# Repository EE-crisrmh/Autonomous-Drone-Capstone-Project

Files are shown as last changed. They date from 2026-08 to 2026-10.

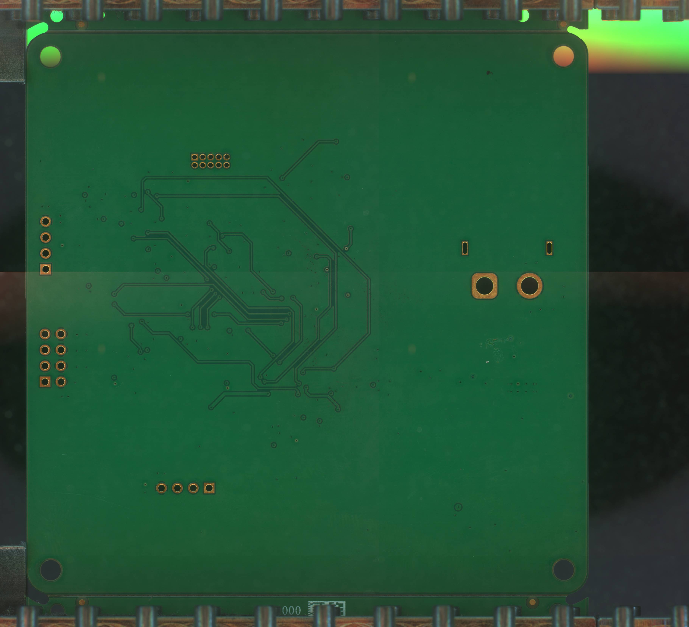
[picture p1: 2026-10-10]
Hardware/images/FlightControllerv1.0_bottom.jpg

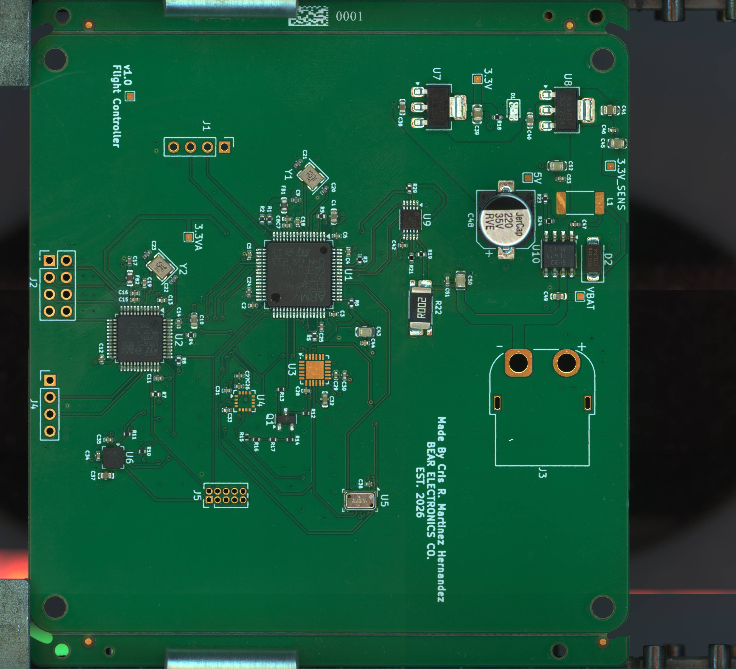
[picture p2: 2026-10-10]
Hardware/images/FlightControllerv1.0_top.jpg

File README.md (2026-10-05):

# LumaWay 🌄

> **A GPS-guided autonomous drone system that guides lost hikers back to safety.**

---

## The Problem

Every year, thousands of hikers get lost on trails across the United States. Terrain looks the same in every direction. Cell service is gone. Panic sets in. Search and rescue teams can take hours to respond — and in the mountains, hours matter.

Current solutions require hikers to stay still and wait. LumaWay flips that. Instead of waiting to be found, the hiker gets found — and then guided home.

---

## What LumaWay Does

LumaWay is an autonomous drone system built for one purpose: get a lost hiker back on the trail.

Here's how it works:

1. **Before the hike**, the hiker opens the LumaWay app and starts a session. The app passively records their GPS trail as they walk in — no interaction needed, just like a fitness tracker running in the background.

2. **If they get lost**, they hit the SOS button. The app sends their current GPS location and their recorded trail path to the LumaWay ground station.

3. **The drone launches autonomously**, navigates to the hiker's GPS coordinates, and locates them.

4. **LumaWay leads them out.** The drone flies the recorded trail path in reverse — slowly, at walking pace — using a bright LED and audio signal to guide the hiker back to the trailhead. Follow the light. That's it.

No payload to drop. No complex robotics. Just a reliable, visible guide in the sky when you need it most.

---

## Why a Drone

A drone can cover terrain a person can't. It flies over downed trees, river crossings, and steep ridgelines. It doesn't get lost. It doesn't get tired. And it can reach a hiker in minutes rather than hours.

LumaWay isn't trying to replace search and rescue — it's a first response that buys time, reduces panic, and gets people moving in the right direction before conditions get worse.

---

## The System

LumaWay is built across three integrated components:

**Custom Flight Controller (Hardware)**
A 4-layer custom PCB built around dual STM32 microcontrollers — one for navigation, one for I/O. Onboard sensors include dual IMUs (ICM-20689, ICM-20602), a barometer (MS5611), and a magnetometer (IST8310) for full attitude and altitude awareness. Designed and manufactured in-house.

**Onboard Computing (Autonomy)**
An NVIDIA Jetson Nano handles high-level autonomy — GPS waypoint navigation, computer vision for hiker confirmation, and communication with the ground station over a wireless link.

**LumaWay App (Interface)**
A mobile app for hikers. Records the trail on the way in. Sends SOS with one tap. Shows the drone's live position on a map so rescue coordinators can monitor the situation in real time.

---

## Project Goals

- Demonstrate fully autonomous GPS-guided navigation to a target location
- Achieve stable hover and guided return-path flight in outdoor conditions
- Build a functional mobile app with trail recording and SOS capability
- Integrate onboard vision for hiker detection and confirmation
- Complete a full end-to-end demo: SOS sent → drone launches → hiker guided back

---

## Status

🔧 **In development** — UW Bothell Capstone Project, 2026–2027

---

## Team

Built by a four-person Electrical Engineering capstone team at the University of Washington Bothell, supervised by Dr. Hannachi.

- Cris R. Martinez Hernandez
- Abraham Chen
- Frank Ma
- Howard Sin

---

## Built With

- STM32F405 / STM32F103 (flight controller MCUs)
- NVIDIA Jetson Nano (onboard compute)
- T-Motor MN2806 Antigravity motors
- KiCad (PCB design)
- PlatformIO (firmware)
- Python / OpenCV (computer vision)
- React Native (mobile app)

---

*LumaWay — your way home made easy*

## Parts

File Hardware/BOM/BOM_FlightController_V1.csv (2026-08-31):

Reference designator | Value | Package | LCSC Part # | MPN | Manufacturer | Description | Cost
C24, C25, C27, C30 | 2.2 uF | 402 | C107369 | CL05A225KP5NSNC | Samsung Electro-Mechanics | 2.2uF 10V X5R ceramic cap | 0.0042
C1, C10, C38, C40, C49 | 10uF | 603 | C19702 | CL10A106KP8NNNC | Samsung Electro-Mechanics | CAP CER 10uF 10V X5R 0603 | 0.0125
C2, C3, C4, C5, C6, C7, C8, C11, C12, C13, C14, C15, C16, C18, C19, C26, C29, C33-C36, C42, C44, C46, C51, C53 | 100nF | 402 | C1525 | CL05B104KO5NNNC | Samsung Electro-Mechanics | CAP CER 100nF 16V X7R 0402 | 0.16
C9, C17 | 1uF | 402 | C29266 | CL05A105KO5NNNC | Samsung Electro-Mechanics | CAP CER 1uF 16V X5R 0402 | 0.35
C20, C21, C22, C23 | 10pF | 402 | C32949 | CL05C100JB5NNNC | Samsung Electro-Mechanics | CAP CER 10pF 50V C0G 0402 | 0.24
C28, C31, C47 | 10nF | 402 | C15195 | CL05B103KB5NNNC | Samsung Electro-Mechanics | CAP CER 10nF 50V X7R 0402 | 0.16
C32 | 0.47uF | 603 | C1623 | CL10B474KA8NNNC | Samsung Electro-Mechanics | CAP CER 470nF 25V X7R 0603 | 0.74
C37 | 4.7uF | 603 | C19666 | CL10A475KO8NNNC | Samsung Electro-Mechanics | CAP CER 4.7uF 16V X5R 0603 | 0.12
C39, C41 | 22uF | 805 | C5674 | CL21A226MQQNNNE | Samsung Electro-Mechanics | CAP CER 22uF 6.3V X5R 0805 | 0.28
C43, C45, C50, C52 | 47uF | 805 | C16780 | CL21A476MQYNNNE | Samsung Electro-Mechanics | CAP CER 47uF 6.3V X5R 0805 | 0.56
C48 | 220uF | SMD,D8xL10.5mm | C48935405 | RVE35V220M8X10 | JIERR | CAP ALUM 220uF ±20% 35V SMD | 0.41
D1 | RED | 805 | C19171391 | YLED0805R | YONGYUTAI | LED RED 0805 SMD | 0.82
D2 | B340 | SMA(DO-214AC) | C908680 | SS34 | GOODWORK | DIODE SCHOTTKY 40V SMA(DO-214AC) | 0.53
FB1, FB2 | 120 ohm | 603 | C14709 | BLM18PG121SN1D | muRata | FERRITE BEAD 120Ω 0603 1LN | 0.74
J1 | connector | Through Hole,P=2.54mm | C32713270 | HX PZ2.54-1x4P ZZ | hanxia | CONN HEADER 4POS 2.54mm SINGLE ROW TH | 0.13
J2 | connector | Through Hole,P=2.54mm | C32713277 | HX PZ2.54-2x4P ZZ | hanxia | CONN HEADER 8POS 2.54mm DUAL ROW TH | 0.6
J4 | connector | Through Hole,P=2.54mm | C32713270 | HX PZ2.54-1x4P ZZ | hanxia | CONN HEADER 4POS 2.54mm SINGLE ROW TH | 0.13
J5 | connector | Through Hole,P=1.27mm | C41426986 | A127M01-0B10P51-H10A39 | JXTCONN | CONN HEADER 10POS DUAL ROW TH | 0.38
L1 | 15uH | 2512 SMD,7x6.6mm | C5349699 | APH0630T150M | APV | FIXED IND 15uH 3A 113mΩ SMD,7x6.6mm | 0.4
Q1 | 20V 350mA NPN transistor | SOT-23 | C916372 | MMBT2222A | JSMSEMI | TRANS NPN 20V 350mA SOT-23 | 0.56
R1, R2, R3, R4, R5, R6, R7, R8, R9, R19, R20, R23 | 10k | 603 | C2930027 | FRC0603J103 TS | FOJAN | RES 10kΩ ±5% 100mW 0603 | 0.14
R10, R11 | 4.7k | 603 | C99782 | RC0603FR-074K7L | YAGEO | RES 4.7kΩ ±1% 100mW 0603 | 0.23
R12, R13, R14, R15, R16, R17 | 1.8 ohm | 603 | C2907087 | FRC0603J1R8 TS | FOJAN | RES 1.8Ω ±5% 100mW 0603 | 0.2
R18 | 1k | 402 | C852624 | RT0402BRD071KL | YAGEO | RES 1kΩ ±0.1% 62.5mW 0402 | 1
R21 | 3.3k | 402 | C482167 | CRCW04023K30FKED | VISHAY | RES 3.3kΩ ±1% 63mW 0402 | 0.4
R22 | 2m | 2512 | C2994640 | HoLLR2512-3W-2mR-1% | Milliohm | RES 2mΩ ±1% 3W 2512 | 0.33
R24 | 3.24k | 402 | C3972407 | CRCW04023K24FKED | VISHAY | RES 3.24kΩ ±1% 62.5mW 0402 | 0.42
U1 | STM32F405RGTx | LQFP-64(10x10) | C1337199 | STM32F405RGT7 | ST | Arm Cortex - M4 32b | 12.83
U2 | STM32F103C8Tx | LQFP-48(7x7) | C8734 | STM32F103C8T6 | ST | Arm-Based 32b | 1.44
U3 | ICM-20689 | QFN-24-EP(4x4) | C2649494 | ICM-20689 | TDK InvenSense | 6-axis MEMS motion tracking | 16.5
U4 | ICM-20602 | LGA-16(3x3) | C97633 | ICM-20602 | TDK InvenSense | 6-Axis MEMS motion tracking | 16.5 | Not available rn
U5 | MS5611-01BA | QFN-8(3x5) | C15639 | MS561101BA03-50 | TE Connectivity | Barometric preassure sensor | 7.11 | Not available rn
U6 | IST8310 | LGA-16(3x3) | C2683055 | IST8310 | iSentek | 3D Magnetometer | 5.63 | U5 MS5611 footprint may have minor QFN vs LGA package discrepancy, please verify pad alignment.
U7, U8 | AMS1117-3.3 | SOT-223 | C5205141 | AMS1117-3.3V | JSMSEMI | 800mA Bipolar Linear Regulator | 0.4
U9 | INA226 | VSOP-10 | C49851 | INA226AIDGSR | TI | Bi-Directional CURRENT/POWER MONITOR with I2C Interface | 0.79
U10 | TPS5430DDA | SOIC-8-EP | C9864 | TPS5430DDAR | TI | 3-A, Wide Input Range, Step-Down Converter | 0.81
Y1, Y2 | 16MHz | SMD3225-4P | C13738 | X322516MLB4SI | YXC Crystal Oscillators | CRYSTAL 16MHz 9pF SMD | 0.49
J3 | connector | AMASS XT60PW-F 1x02 P7.20mm Horizontal | C428722 | XT60PW-F | Changzhou Amass Elec | Power Connectors | 0.64

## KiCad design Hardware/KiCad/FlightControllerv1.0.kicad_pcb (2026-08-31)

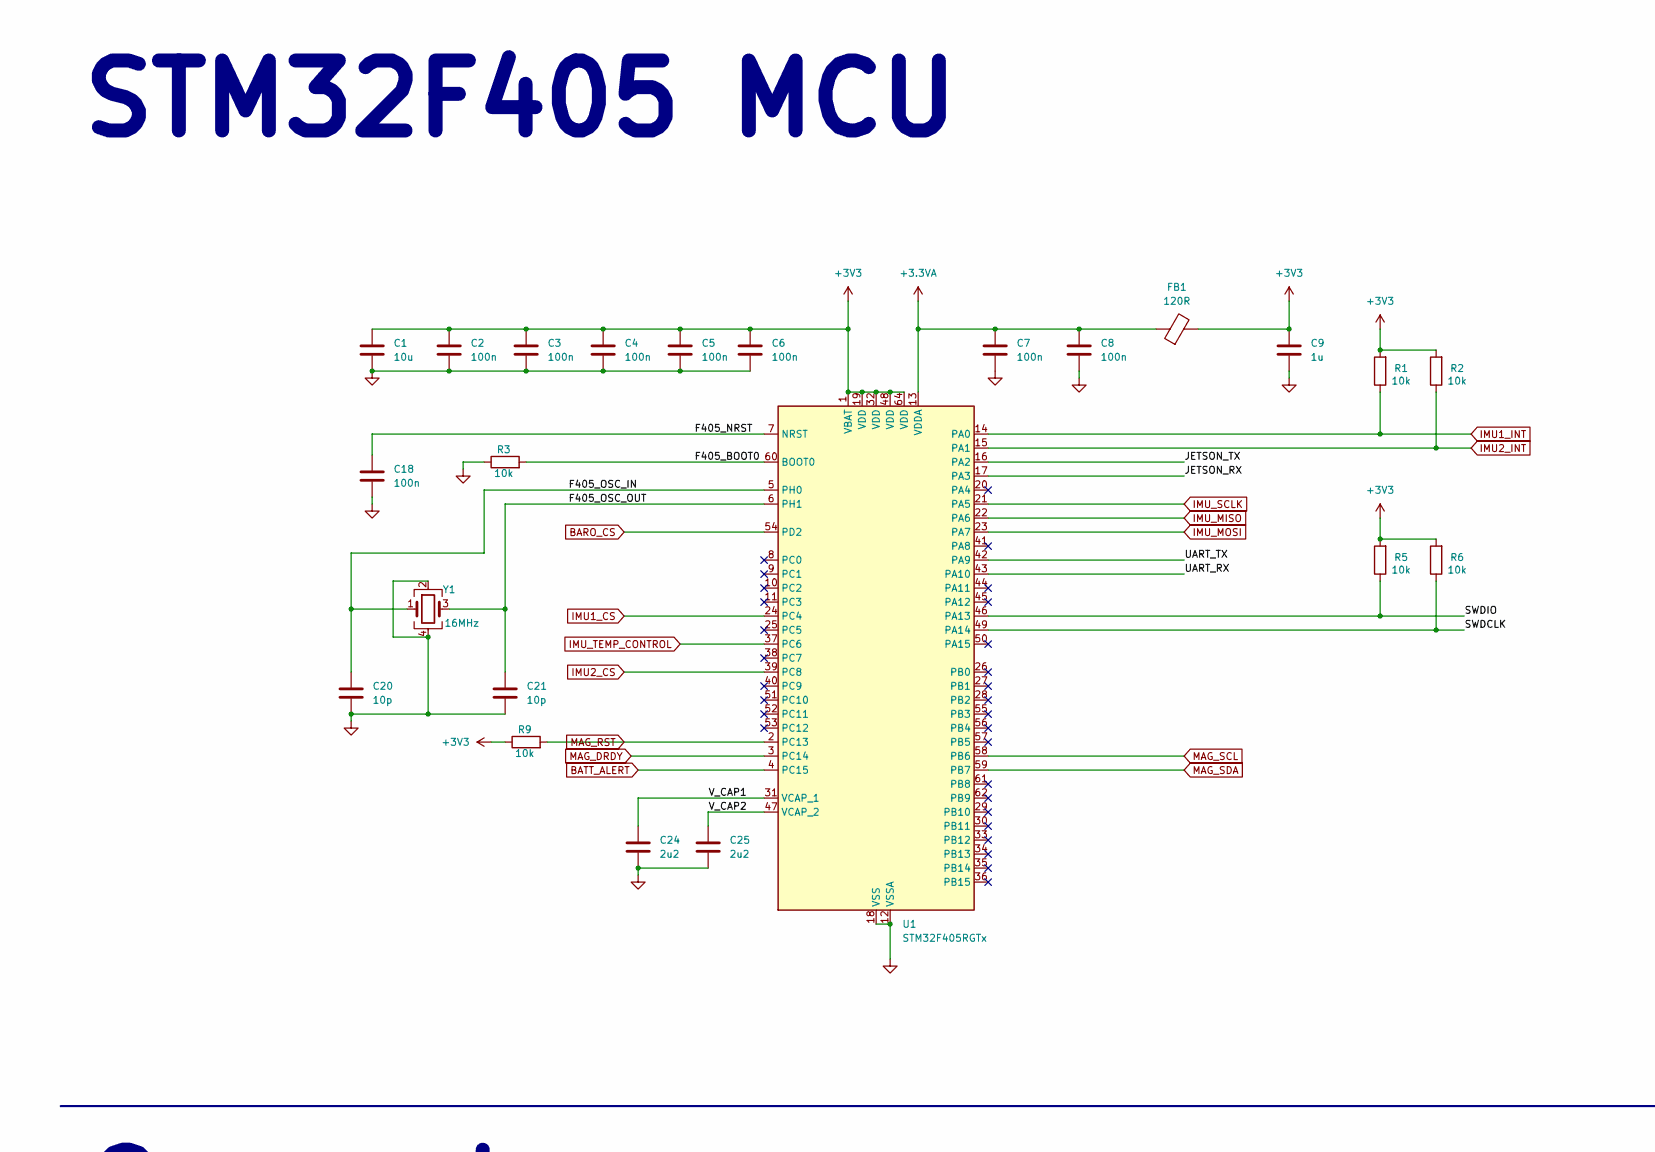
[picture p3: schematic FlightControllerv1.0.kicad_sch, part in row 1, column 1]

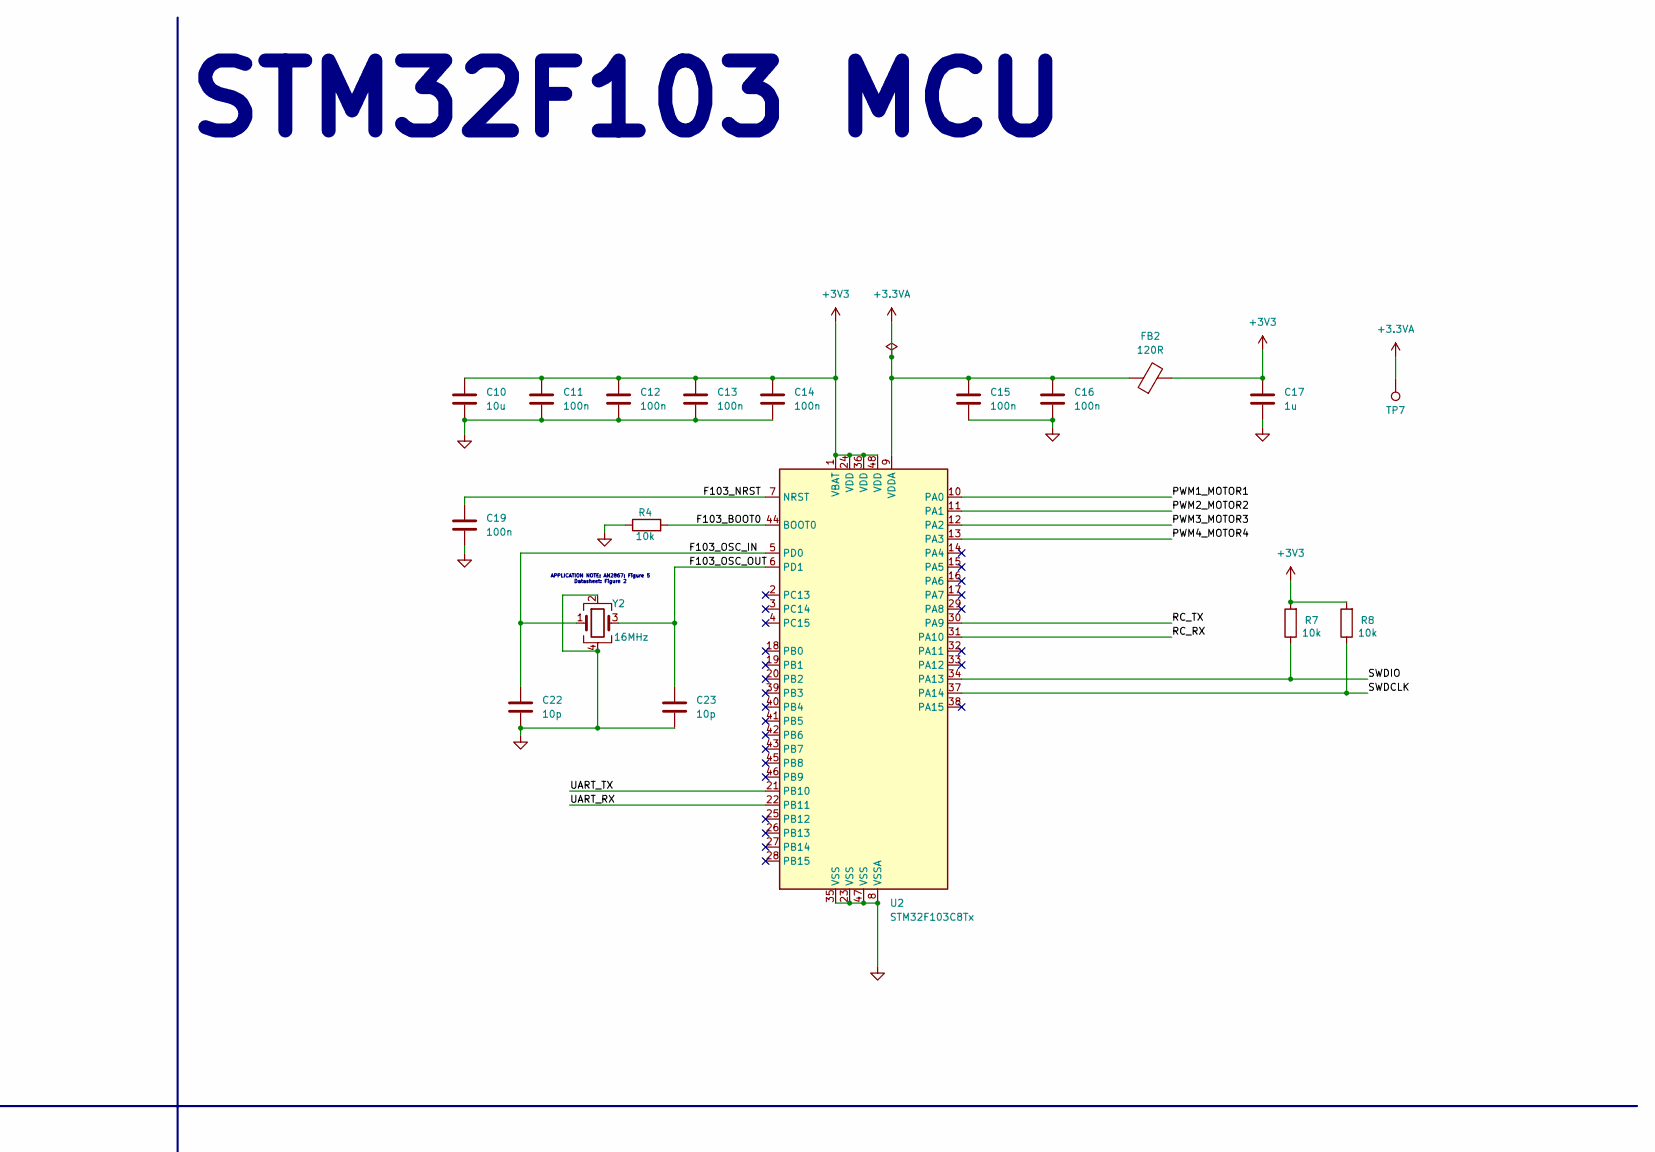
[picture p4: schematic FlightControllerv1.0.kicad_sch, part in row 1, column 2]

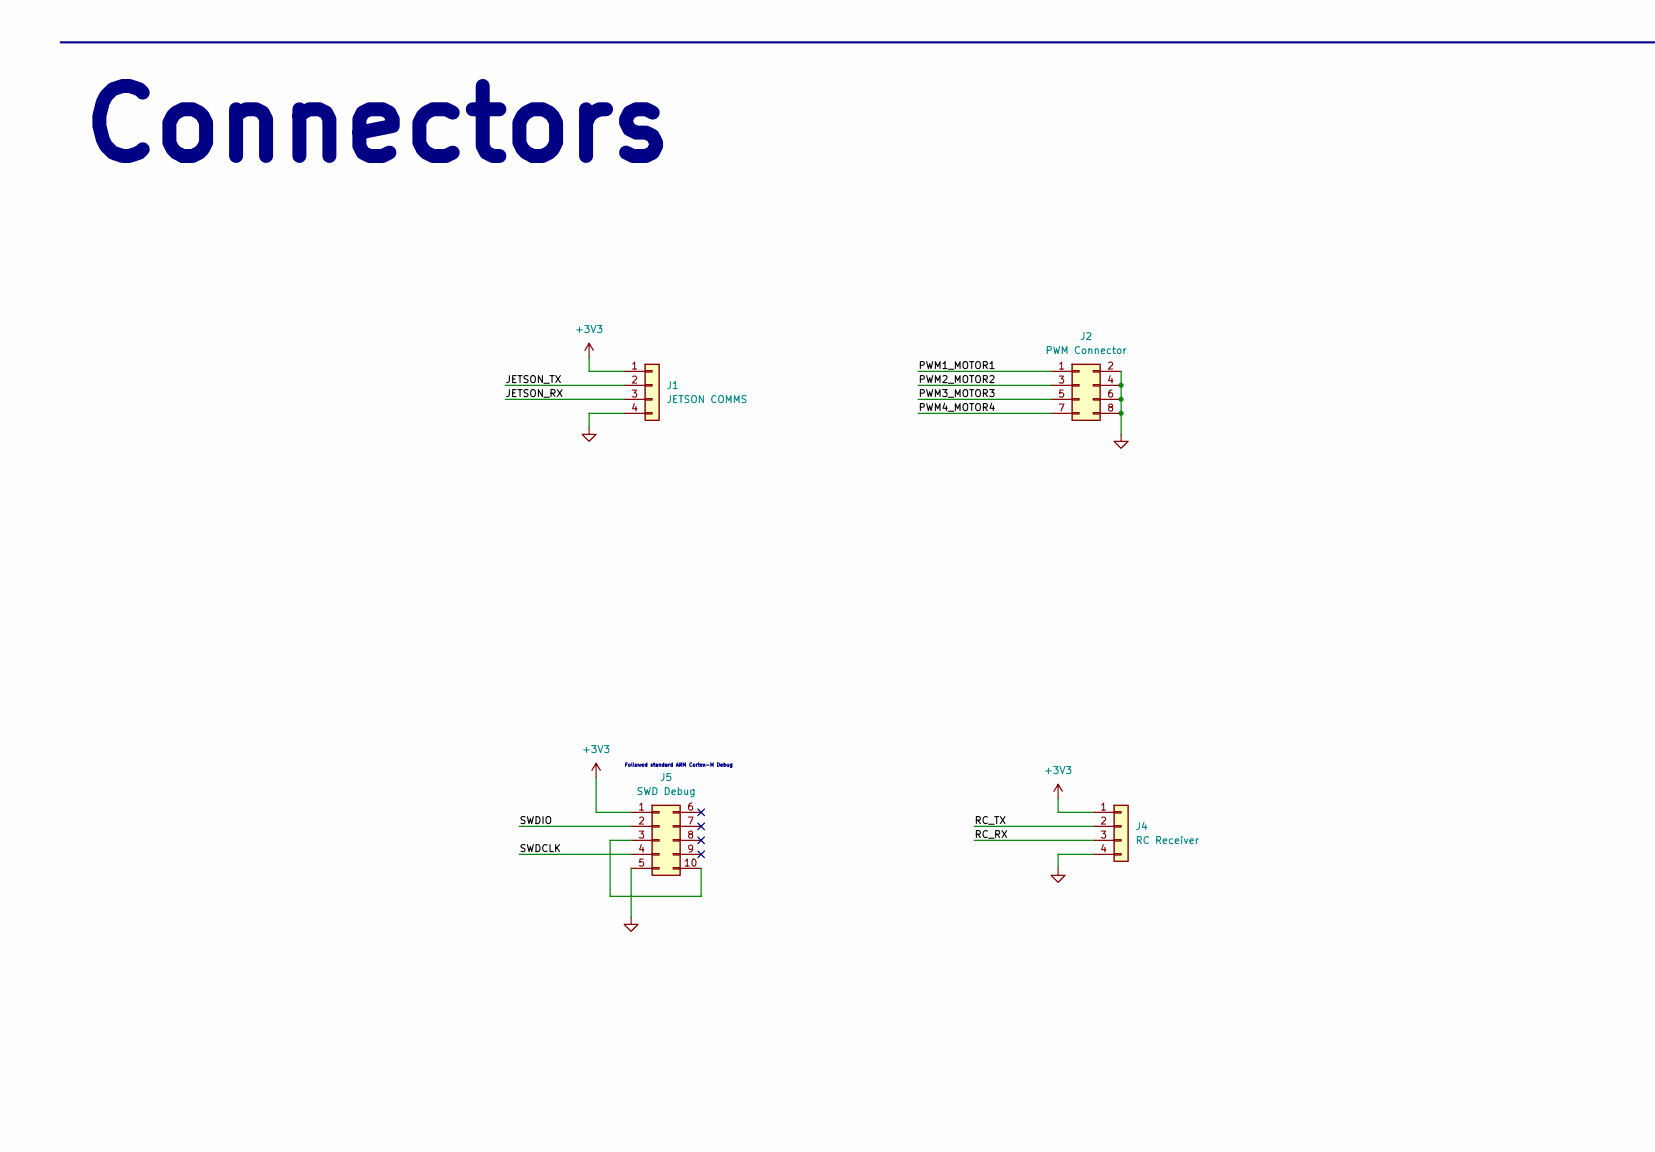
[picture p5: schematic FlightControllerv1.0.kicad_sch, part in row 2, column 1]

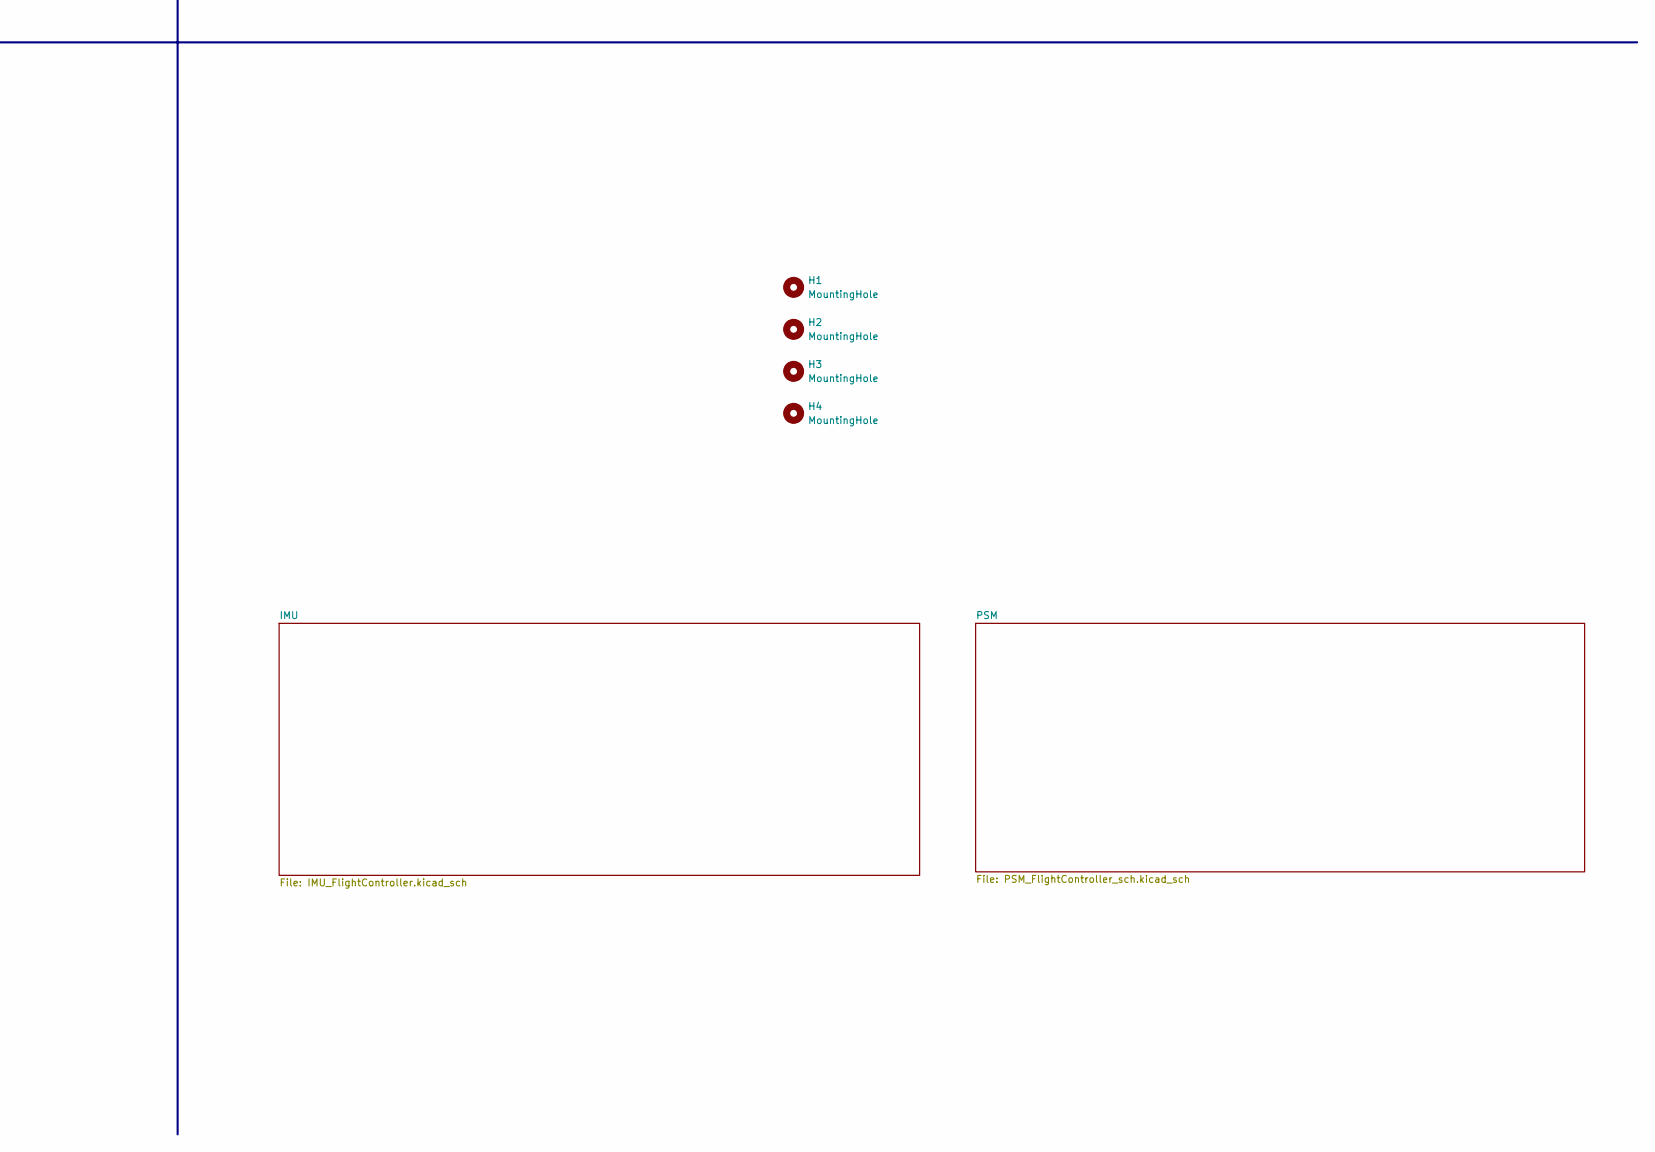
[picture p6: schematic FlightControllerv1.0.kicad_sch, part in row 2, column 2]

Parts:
C1, C10: 10u; C_0603_1608Metric
C2, C3, C4, C5, C6, C7, C8, C11, C12, C13, C14, C15, C16, C18, C19: 100n; C_0402_1005Metric
C9, C17: 1u; C_0402_1005Metric
C20, C21, C22, C23: 10p; C_0402_1005Metric
C24, C25: 2u2; C_0402_1005Metric
FB1, FB2: 120R; L_0603_1608Metric
H1, H2, H3, H4: MountingHole; MountingHole_3.2mm_M3
J1: JETSON COMMS; PinHeader_1x04_P2.54mm_Vertical
J2: PWM Connector; PinHeader_2x04_P2.54mm_Vertical
J4: RC Receiver; PinHeader_1x04_P2.54mm_Vertical
J5: SWD Debug; PinHeader_2x05_P1.27mm_Vertical
R1, R2, R3, R4, R5, R6, R7, R8, R9: 10k; R_0402_1005Metric
TP7: TestPoint; TestPoint_Pad_1.0x1.0mm
U1: STM32F405RGTx; LQFP-64_10x10mm_P0.5mm
U2: STM32F103C8Tx; LQFP-48_7x7mm_P0.5mm
Y1, Y2: 16MHz; Crystal_SMD_3225-4Pin_3.2x2.5mm

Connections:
+3.3VA: C7.1, C8.1, C15.1, C16.1, FB1.1, FB2.1, TP7.1, U1.13 (VDDA), U2.9 (VDDA); also elsewhere on the board
+3V3: C1.1, C2.1, C3.1, C4.1, C5.1, C6.1, C9.1, C10.1, C11.1, C12.1, C13.1, C14.1, C17.1, FB1.2, FB2.2, J1.1, J4.1, J5.1, R1.2, R2.2, R5.2, R6.2, R7.2, R8.2, R9.1, U1.1 (VBAT), U1.19 (VDD), U1.32 (VDD), U1.48 (VDD), U1.64 (VDD), U2.1 (VBAT), U2.24 (VDD), U2.36 (VDD), U2.48 (VDD); also elsewhere on the board
/F103_BOOT0: R4.2, U2.44 (BOOT0)
/F103_NRST: C19.1, U2.7 (NRST)
/F103_OSC_IN: C22.1, U2.5 (PD0), Y2.1
/F103_OSC_OUT: C23.1, U2.6 (PD1), Y2.3
/F405_BOOT0: R3.2, U1.60 (BOOT0)
/F405_NRST: C18.1, U1.7 (NRST)
/F405_OSC_IN: C20.1, U1.5 (PH0), Y1.1
/F405_OSC_OUT: C21.1, U1.6 (PH1), Y1.3
/JETSON_RX: J1.3, U1.17 (PA3)
/JETSON_TX: J1.2, U1.16 (PA2)
/PWM1_MOTOR1: J2.1, U2.10 (PA0)
/PWM2_MOTOR2: J2.3, U2.11 (PA1)
/PWM3_MOTOR3: J2.5, U2.12 (PA2)
/PWM4_MOTOR4: J2.7, U2.13 (PA3)
/RC_RX: J4.3, U2.31 (PA10)
/RC_TX: J4.2, U2.30 (PA9)
/SWDCLK: J5.4, R6.1, R8.1, U1.49 (PA14), U2.37 (PA14)
/SWDIO: J5.2, R5.1, R7.1, U1.46 (PA13), U2.34 (PA13)
/UART_RX: U1.43 (PA10), U2.22 (PB11)
/UART_TX: U1.42 (PA9), U2.21 (PB10)
/V_CAP1: C24.1, U1.31 (VCAP_1)
/V_CAP2: C25.1, U1.47 (VCAP_2)
BARO_CS: U1.54 (PD2); also elsewhere on the board
BATT_ALERT: U1.4 (PC15); also elsewhere on the board
GND: C1.2, C2.2, C3.2, C4.2, C5.2, C6.2, C7.2, C8.2, C9.2, C10.2, C11.2, C12.2, C13.2, C14.2, C15.2, C16.2, C17.2, C18.2, C19.2, C20.2, C21.2, C22.2, C23.2, C24.2, C25.2, J1.4, J2.2, J2.4, J2.6, J2.8, J4.4, J5.5, R3.1, R4.1, U1.12 (VSSA), U1.18 (VSS), U1.63 (VSS), U2.8 (VSSA), U2.23 (VSS), U2.35 (VSS), U2.47 (VSS), Y1.2, Y1.4, Y2.2, Y2.4; also elsewhere on the board
IMU1_CS: U1.24 (PC4); also elsewhere on the board
IMU1_INT: R1.1, U1.14 (PA0); also elsewhere on the board
IMU2_CS: U1.39 (PC8); also elsewhere on the board
IMU2_INT: R2.1, U1.15 (PA1); also elsewhere on the board
IMU_MISO: U1.22 (PA6); also elsewhere on the board
IMU_MOSI: U1.23 (PA7); also elsewhere on the board
IMU_SCLK: U1.21 (PA5); also elsewhere on the board
IMU_TEMP_CONTROL: U1.37 (PC6); also elsewhere on the board
MAG_DRDY: U1.3 (PC14); also elsewhere on the board
MAG_RST: R9.2, U1.2 (PC13); also elsewhere on the board
MAG_SCL: U1.58 (PB6); also elsewhere on the board
MAG_SDA: U1.59 (PB7); also elsewhere on the board
unnamed: J5.3, J5.10

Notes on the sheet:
APPLICATION NOTE: AN2867: Figure 5 Datasheet: Figure 2
STM32F103 MCU
STM32F405 MCU
Followed standard ARM Cortex-M Debug
Connectors

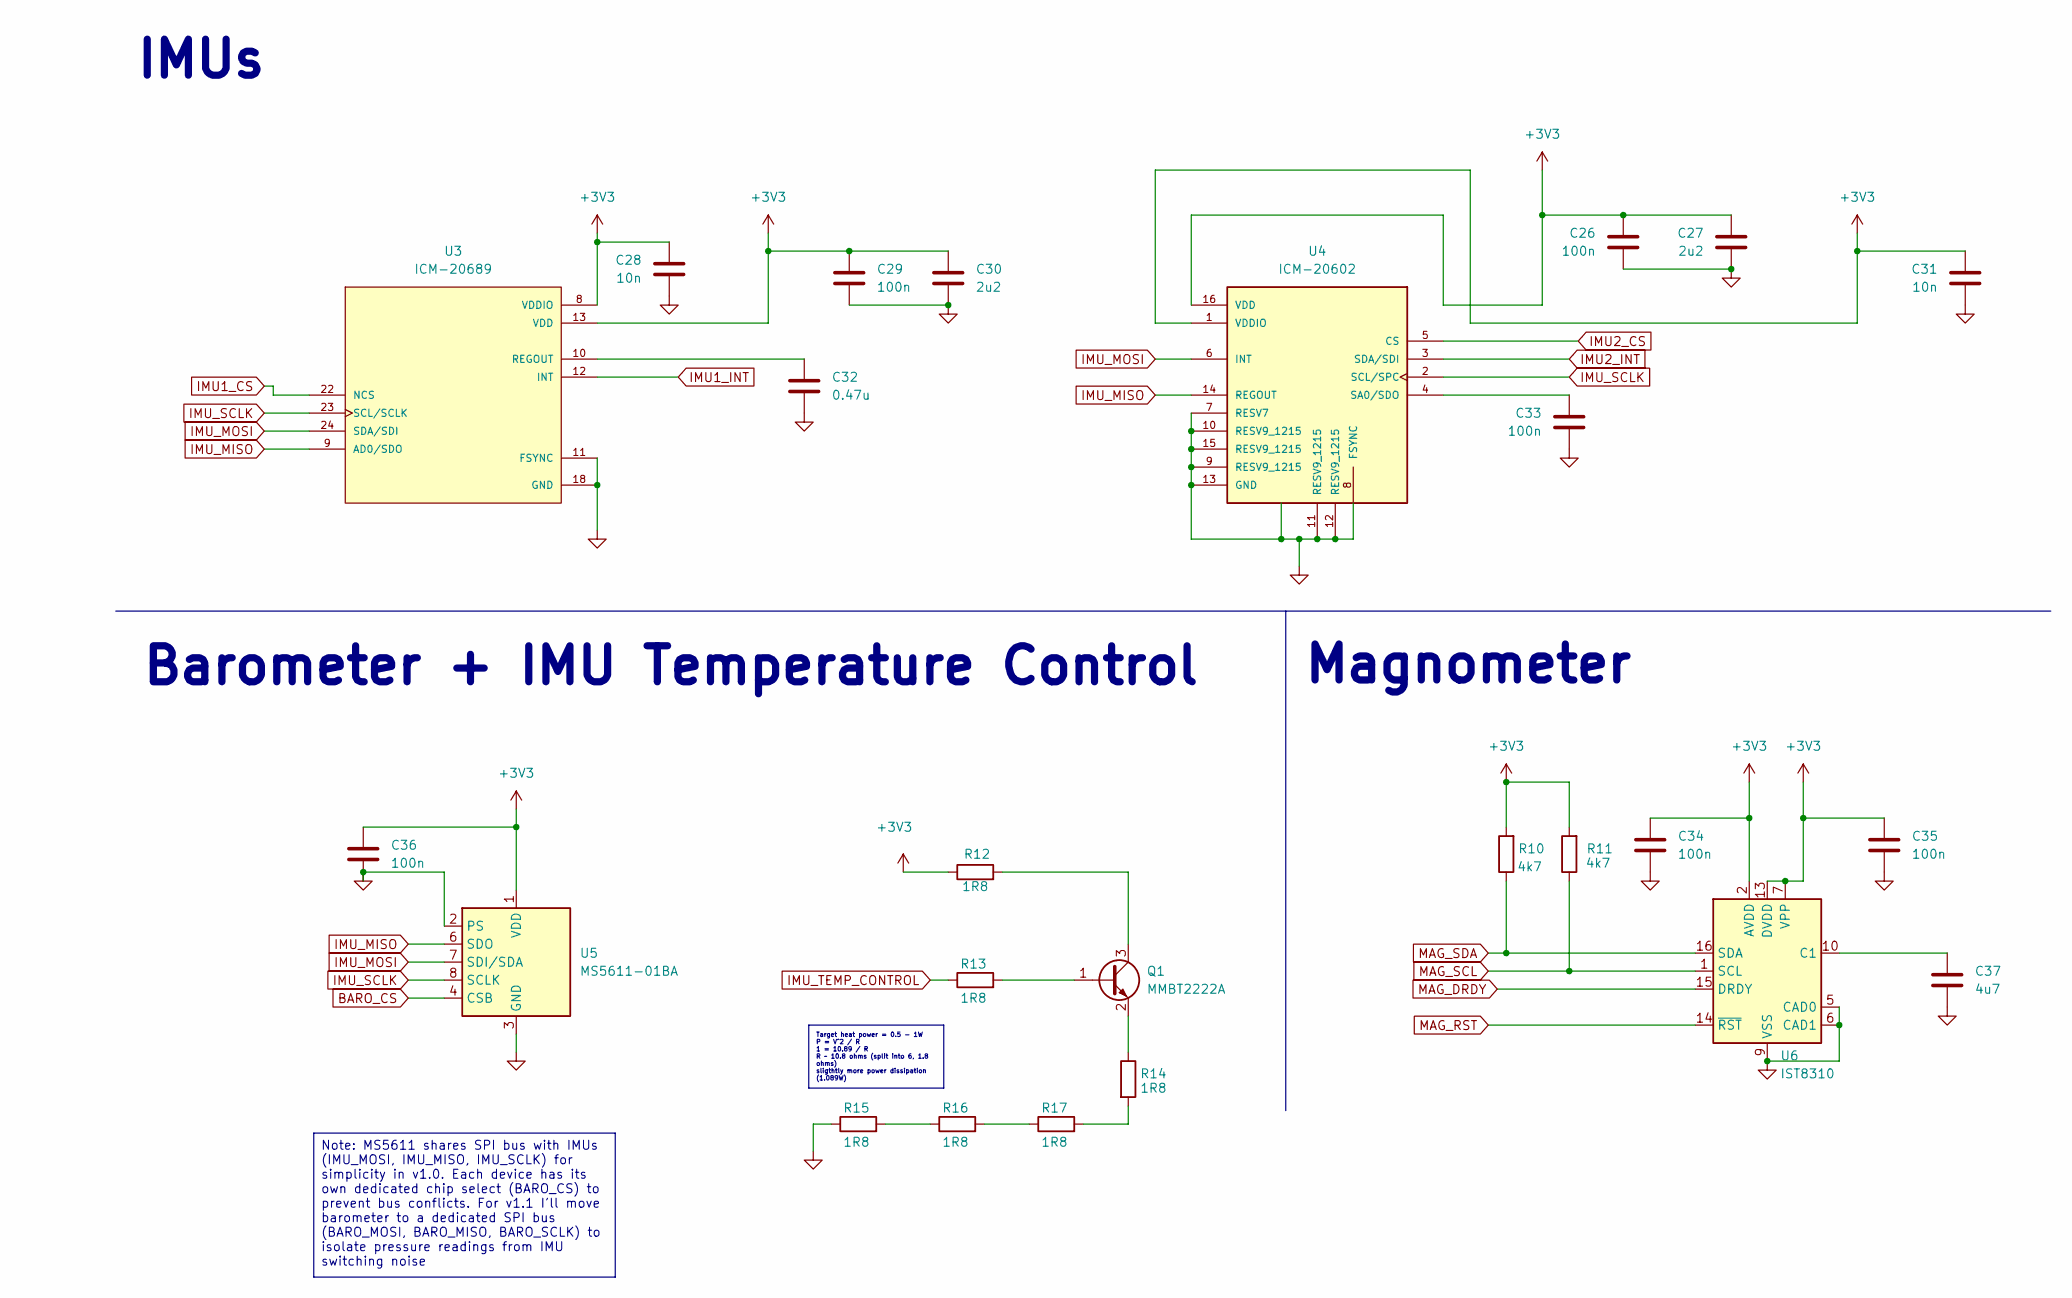
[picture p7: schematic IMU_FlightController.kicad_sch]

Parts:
C26, C29, C33, C34, C35, C36: 100n; C_0402_1005Metric
C27, C30: 2u2; C_0402_1005Metric
C28, C31: 10n; C_0402_1005Metric
C32: 0.47u; C_0603_1608Metric
C37: 4u7; C_0603_1608Metric
Q1: MMBT2222A; SOT-23
R10, R11: 4k7; R_0201_0603Metric
R12, R13, R14, R15, R16, R17: 1R8; R_0201_0603Metric
U3: ICM-20689; QFN-24-1EP_4x4mm_P0.5mm_EP2.65x2.65mm
U4: ICM-20602; LGA-16_3x3mm_P0.5mm
U5: MS5611-01BA; LGA-8_3x5mm_P1.25mm
U6: IST8310; LGA-16_3x3mm_P0.5mm

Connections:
+3V3: C26.1, C27.1, C28.1, C29.1, C30.1, C31.1, C34.1, C35.1, C36.1, R10.2, R11.2, R12.1, U3.8 (VDDIO), U3.13 (VDD), U4.1 (VDDIO), U4.16 (VDD), U5.1 (VDD), U6.2 (AVDD), U6.7 (VPP), U6.13 (DVDD); also elsewhere on the board
BARO_CS: U5.4 (CSB), U5.5 (CSB); also elsewhere on the board
GND: C26.2, C27.2, C28.2, C29.2, C30.2, C31.2, C32.2, C33.2, C34.2, C35.2, C36.2, C37.2, R15.1, U3.11 (FSYNC), U3.18 (GND), U4.7 (RESV7), U4.8 (FSYNC), U4.9 (RESV9_1215), U4.10 (RESV9_1215), U4.11 (RESV9_1215), U4.12 (RESV9_1215), U4.13 (GND), U4.15 (RESV9_1215), U5.2 (PS), U5.3 (GND), U6.5 (CAD0), U6.6 (CAD1), U6.9 (VSS), U6.11 (VSS); also elsewhere on the board
IMU1_CS: U3.22 (NCS); also elsewhere on the board
IMU1_INT: U3.12 (INT); also elsewhere on the board
IMU2_CS: U4.5 (CS); also elsewhere on the board
IMU2_INT: U4.3 (SDA/SDI); also elsewhere on the board
IMU_MISO: U3.9 (AD0/SDO), U4.14 (REGOUT), U5.6 (SDO); also elsewhere on the board
IMU_MOSI: U3.24 (SDA/SDI), U4.6 (INT), U5.7 (SDI/SDA); also elsewhere on the board
IMU_SCLK: U3.23 (SCL/SCLK), U4.2 (SCL/SPC), U5.8 (SCLK); also elsewhere on the board
IMU_TEMP_CONTROL: R13.1; also elsewhere on the board
MAG_DRDY: U6.15 (DRDY); also elsewhere on the board
MAG_RST: U6.14 (~RST); also elsewhere on the board
MAG_SCL: R11.1, U6.1 (SCL); also elsewhere on the board
MAG_SDA: R10.1, U6.16 (SDA); also elsewhere on the board
unnamed: Q1.1 (B), R13.2
unnamed: Q1.3 (C), R12.2
unnamed: Q1.2 (E), R14.1
unnamed: R14.2, R17.2
unnamed: R15.2, R16.1
unnamed: R16.2, R17.1
unnamed: C32.1, U3.10 (REGOUT)
unnamed: C33.1, U4.4 (SA0/SDO)
unnamed: C37.1, U6.10 (C1)

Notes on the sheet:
Barometer + IMU Temperature Control
Magnometer
IMUs
Note: MS5611 shares SPI bus with IMUs (IMU_MOSI, IMU_MISO, IMU_SCLK) for simplicity in v1.0. Each device has its own dedicated chip select (BARO_CS) to prevent bus conflicts. For v1.1 I'll move barometer to a dedicated SPI bus (BARO_MOSI, BARO_MISO, BARO_SCLK) to isolate pressure readings from IMU 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
Target heat power = 0.5 - 1W P = V^2 / R 1 = 10.89 / R R ~ 10.8 ohms (split into 6, 1.8 ohms) sligthtly more power dissipation (1.089W)

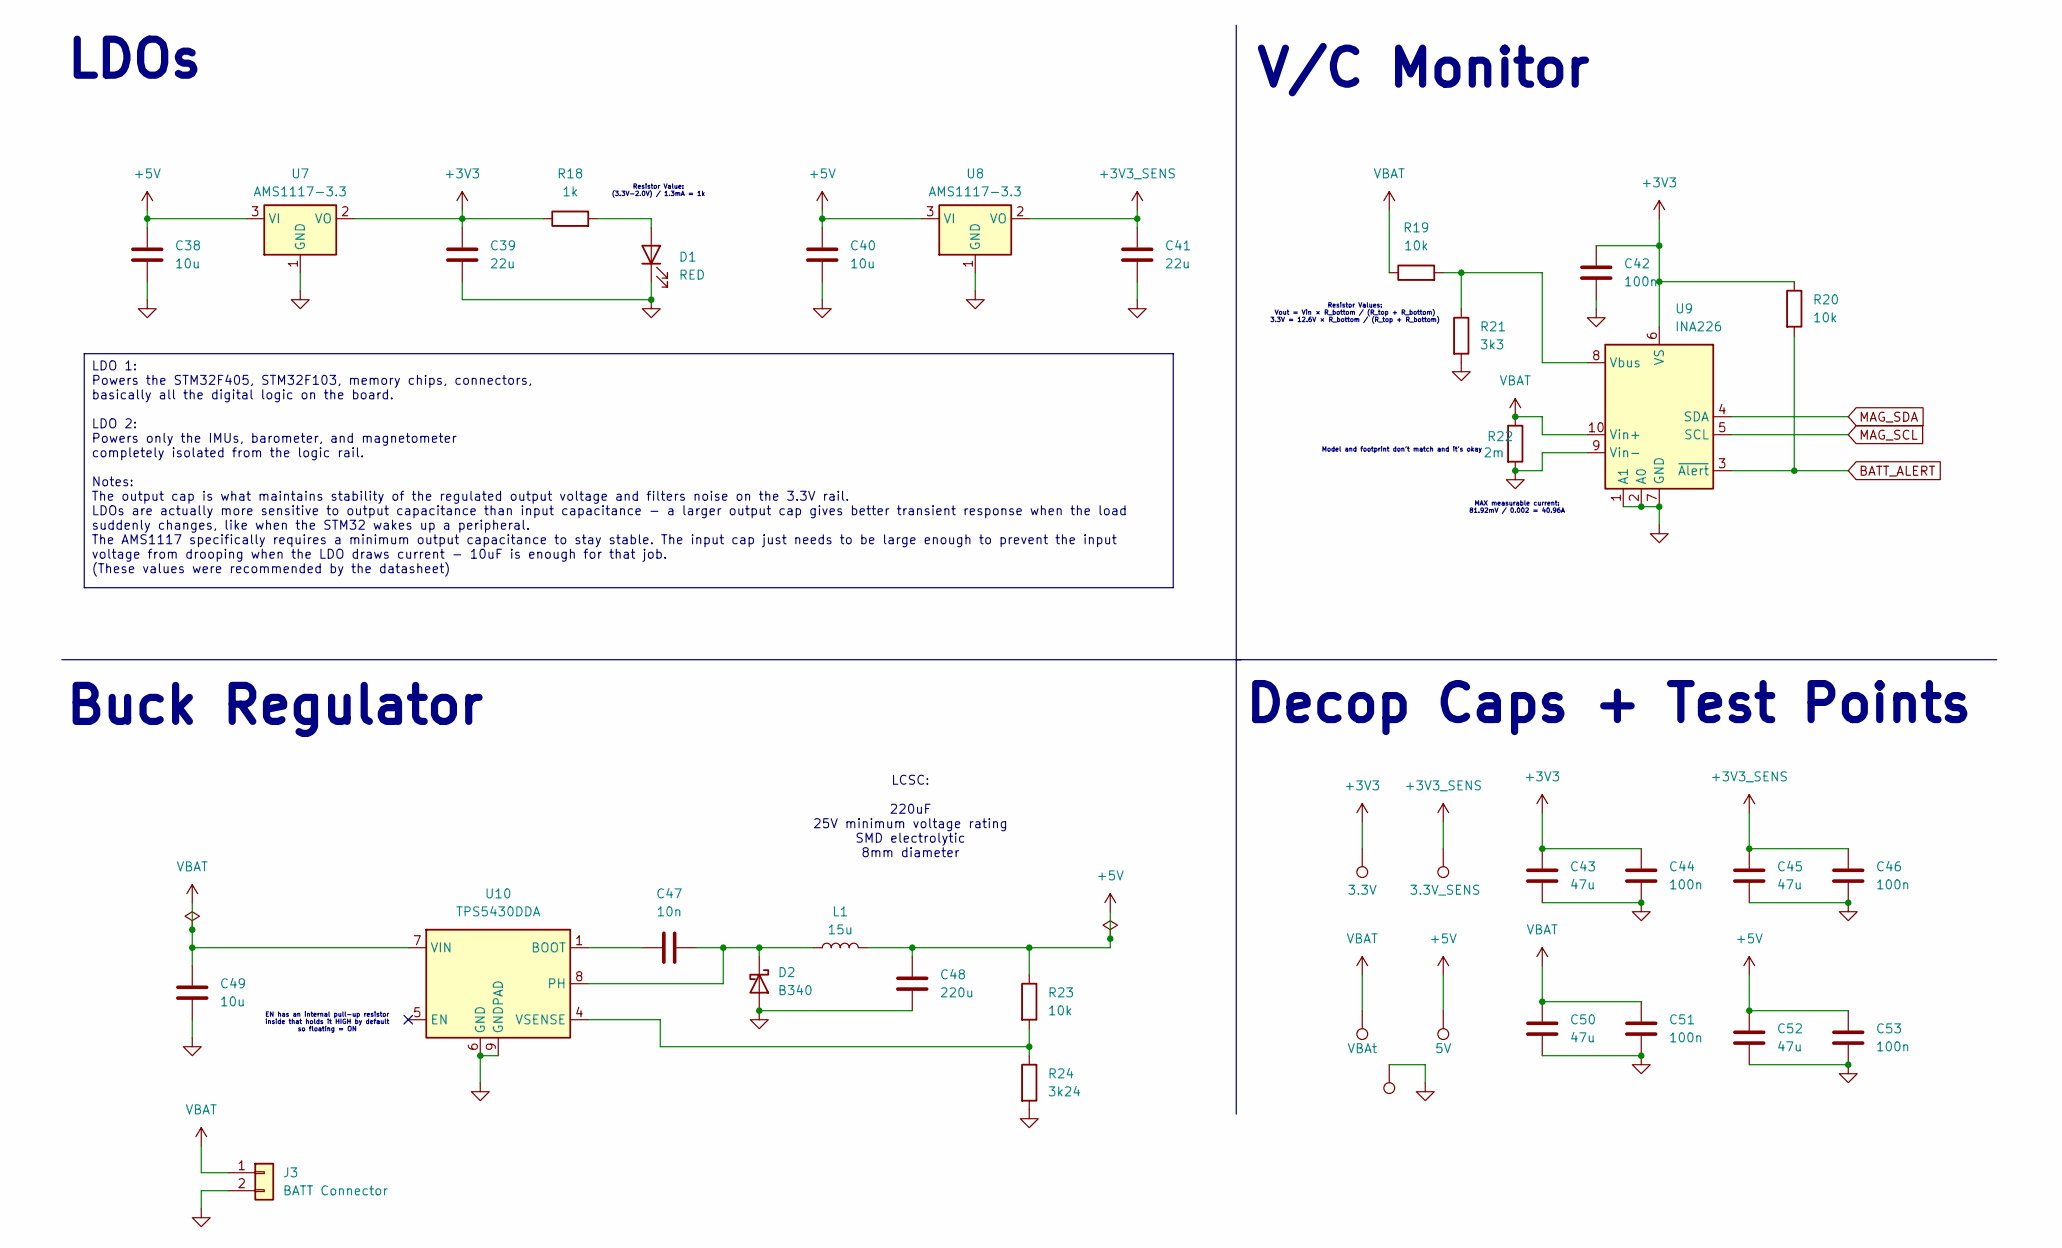
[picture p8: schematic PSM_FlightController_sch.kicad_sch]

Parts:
3.3V, 3.3V_SENS, 5V: TestPoint; TestPoint_Pad_1.0x1.0mm
C38, C40, C49: 10u; C_0603_1608Metric
C39, C41: 22u; C_0805_2012Metric
C42, C44, C46, C51, C53: 100n; C_0402_1005Metric
C43, C45, C50, C52: 47u; C_0805_2012Metric
C47: 10n; C_0402_1005Metric
C48: 220u; CP_Elec_8x10.5
D1: RED; LED_0805_2012Metric
D2: B340; D_SMA
J3: BATT Connector; AMASS_XT60PW-F_1x02_P7.20mm_Horizontal
L1: 15u; L_2512_6332Metric
R18: 1k; R_0402_1005Metric
R19, R20, R23: 10k; R_0402_1005Metric
R21: 3k3; R_0402_1005Metric
R22: 2m; R_Shunt_Vishay_WSK2512_6332Metric_T1.19mm
R24: 3k24; R_0402_1005Metric
TP5: TestPoint; TestPoint_Pad_1.0x1.0mm
U7, U8: AMS1117-3.3; SOT-223-3_TabPin2
U9: INA226; VSSOP-10_3x3mm_P0.5mm
U10: TPS5430DDA; TI_SO-PowerPAD-8_ThermalVias
VBAt: TestPoint; TestPoint_Pad_1.0x1.0mm

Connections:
+3V3: 3.3V.1, C39.1, C42.2, C43.2, C44.2, R18.1, R20.1, U7.2 (VO), U9.6 (VS); also elsewhere on the board
+3V3_SENS: 3.3V_SENS.1, C41.1, C45.2, C46.2, U8.2 (VO)
+5V: 5V.1, C38.1, C40.1, C48.2, C52.2, C53.2, L1.2, R23.1, U7.3 (VI), U8.3 (VI)
BATT_ALERT: R20.2, U9.3 (~Alert); also elsewhere on the board
GND: C38.2, C39.2, C40.2, C41.2, C42.1, C43.1, C44.1, C45.1, C46.1, C48.1, C49.2, C50.1, C51.1, C52.1, C53.1, D1.1 (K), D2.2 (A), J3.2, R21.2, R22.2, R24.2, TP5.1, U7.1 (GND), U8.1 (GND), U9.1 (A1), U9.2 (A0), U9.7 (GND), U9.9 (Vin-), U10.6 (GND), U10.9 (GNDPAD); also elsewhere on the board
MAG_SCL: U9.5 (SCL); also elsewhere on the board
MAG_SDA: U9.4 (SDA); also elsewhere on the board
unnamed: D1.2 (A), R18.2
unnamed: C47.2, D2.1 (K), L1.1, U10.8 (PH)
unnamed: R19.2, R21.1, U9.8 (Vbus)
unnamed: C47.1, U10.1 (BOOT)
unnamed: R23.2, R24.1, U10.4 (VSENSE)
VBAT: C49.1, C50.2, C51.2, J3.1, R19.1, R22.1, U9.10 (Vin+), U10.7 (VIN), VBAt.1; also elsewhere on the board

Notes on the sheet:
LCSC: 220uF 25V minimum voltage rating SMD electrolytic 8mm diameter
Buck Regulator
Resistor Values: Vout = Vin × R_bottom / (R_top + R_bottom) 3.3V = 12.6V × R_bottom / (R_top + R_bottom)
Model and footprint don't match and it's okay
Resistor Value: (3.3V-2.0V) / 1.3mA = 1k
V/C Monitor
EN has an internal pull-up resistor inside that holds it HIGH by default so floating = ON
MAX measurable current: 81.92mV / 0.002 = 40.96A
Decop Caps + Test Points
LDOs
LDO 1: Powers the STM32F405, STM32F103, memory chips, connectors, basically all the digital logic on the board. LDO 2: Powers only the IMUs, barometer, and magnetometer completely isolated from the logic rail. Notes: The output cap is what maintains stability of the regulated output voltage and fil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

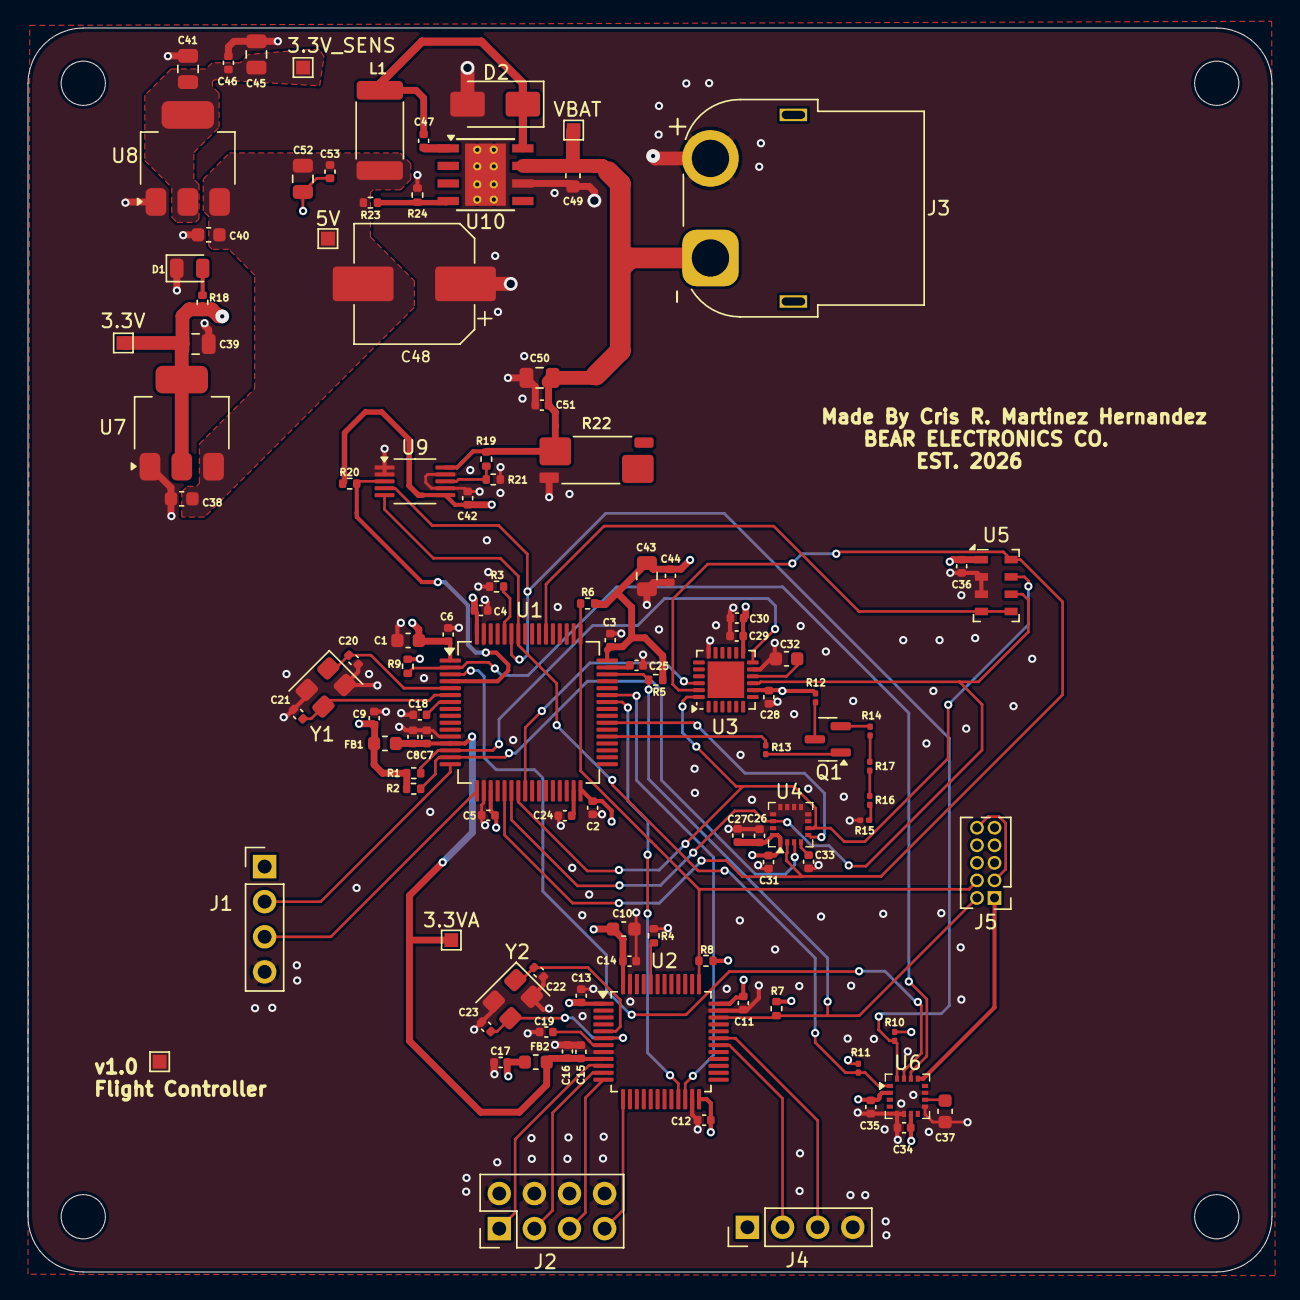
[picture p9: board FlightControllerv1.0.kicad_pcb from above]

Board: 4 copper layers, 90.0 x 90.0 mm, 110 parts (0 on the bottom side), 57 nets.

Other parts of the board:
3.3VA: TestPoint; TestPoint_Pad_1.0x1.0mm
VBAT: TestPoint; TestPoint_Pad_1.0x1.0mm

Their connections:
+3.3VA: 3.3VA.1; also elsewhere on the board
VBAT: VBAT.1; also elsewhere on the board
